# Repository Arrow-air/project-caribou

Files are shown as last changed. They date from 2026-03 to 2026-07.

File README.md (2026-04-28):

# Project Caribou 🦌

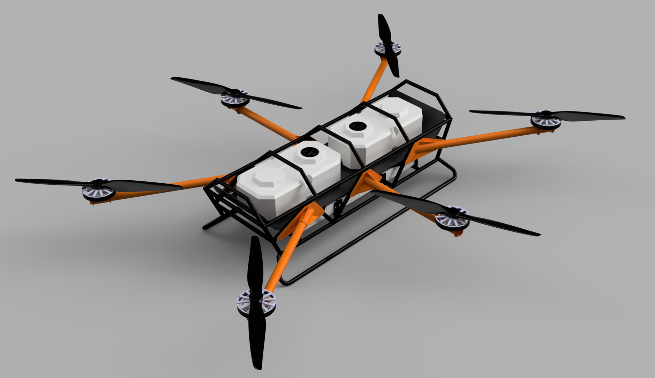
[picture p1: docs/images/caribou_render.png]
Project Caribou


**An open-source heavy-lift hexacopter for cargo logistics and precision agriculture.**

Project Caribou is a ~200 kg MTOW hexacopter with ~100 kg payload capacity, 18–24S power architecture, and ArduPilot firmware. Designed for ruggedness, field repairability, and cost-effective manufacturing. Built on lessons from Project Feather and Project Quiver.

Developed by [Arrow Air](https://arrowair.com) and released under the CERN Open Hardware Licence.

## Key Features

- **Heavy lift** — ~100 kg payload for cargo delivery or 80L liquid spraying
- **Hybrid material airframe** — welded steel/aluminum core with detachable CF or aluminum motor arms
- **High-voltage architecture** — 18–24S (60–100V) with external HV kill switch and redundant power supply
- **Redundant avionics** — triple-redundant IMU, GPS, and compass
- **ArduPilot firmware** — standard QGroundControl/Mission Planner compatibility
- **Field serviceability** — modular arms for transport, replaceable components

## Repository Structure

```
project-caribou/
├── engineering/            # Active design work
│   ├── cad/                # build123d CAD, reference geometry, exports
│   └── electronics/        # Self-contained KiCad PCB projects
│       └── pcbs/
│           ├── CBC_PCB/    # Caribou battery connector PCB, issue #6
│           │   └── kicad/libs/
│           └── CMAIN_PCB/  # Caribou main PCB, issue #8
│               └── kicad/libs/
├── docs/
│   ├── ADRs/               # Architecture Decision Records
│   └── meetings/           # Meeting notes and summaries
├── src/                    # Legacy/general source area
└── CONTRIBUTING.md
```

## Community

- **Discord** — [discord.gg/arrow](https://discord.gg/arrow) — `#project-caribou-general`
- **DAO Forum** — [dao.arrowair.com](https://dao.arrowair.com)

## License

[CERN Open Hardware Licence Version 2 - Strongly Reciprocal (CERN-OHL-S)](https://ohwr.org/cern_ohl_s_v2.txt)

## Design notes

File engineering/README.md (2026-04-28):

# Engineering

This folder contains the active design work for Project Caribou.

- `cad/` — mechanical CAD, generated exports, and reference geometry.
- `electronics/` — PCB projects and electronics design files.

Keep durable decisions and explanatory documents in `docs/`. Use GitHub issues and discussions for live work-in-progress updates, then summarize settled outcomes back into the relevant README or ADR.

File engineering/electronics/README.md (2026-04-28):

# Electronics

Caribou electronics design files live here.

## PCB projects

Each PCB has its own self-contained folder under `pcbs/`. KiCad projects should keep project files under `kicad/` and local libraries under `kicad/libs/` so a contributor can clone/download the PCB folder and open it without missing project-specific components.

Current PCB folders:

- `pcbs/CBC_PCB/` — Caribou battery connector PCB. Tracks [issue #6](https://github.com/Arrow-air/project-caribou/issues/6).
- `pcbs/CMAIN_PCB/` — Caribou main PCB. Tracks [issue #8](https://github.com/Arrow-air/project-caribou/issues/8).

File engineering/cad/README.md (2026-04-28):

# CAD

Caribou CAD work lives here.

## Folders

- `build123d/` — Python/build123d parametric CAD source.
- `reference/` — imported vendor, measurement, or reference geometry.
- `build123d/exports/` — generated STEP/STL outputs for review, manufacturing, or downstream CAD use.

Generated exports should be reproducible from the source where practical. If an export is hand-edited or comes from another CAD package, document that in the nearest README.

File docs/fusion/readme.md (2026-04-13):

# Fusion 360 Workspace — Project Caribou

## Folder Structure

```
📁 Caribou_<Name>        — Personal sandbox (each contributor creates their own)
📁 Deprecated             — Move obsolete files here (do NOT delete)
📁 Main_Assembly          — Master Assembly ONLY (no parts, no features)
📁 Parts/
   ├── EL-Electronics
   ├── EN-Enclosure
   ├── PW-Powertrain
   └── ST-Structure
📁 Sub_Assemblies         — Sub-assemblies composed of parts or other sub-assemblies
```

## Naming Convention

### Parts

Format: `<Category>-<Type>-<Number>-<Description>`

| Example | Meaning |
|---|---|
| `ST-FRM-001-Spacer_1` | Structure — Frame — Part 001 |
| `PW-MTR-001-Motor_Mount` | Powertrain — Motor — Part 001 |
| `EL-PCB-001-BMS_Enclosure` | Electronics — PCB — Part 001 |

### Sub-Assemblies

Format: `<Category>-<Description>_Assembly`

| Example | Meaning |
|---|---|
| `PW-Propulsion_System_Assembly` | Powertrain sub-assembly |
| `ST-Frame_Assembly` | Structure sub-assembly |

### Category Prefixes

| Prefix | Category |
|---|---|
| `ST` | Structure |
| `PW` | Powertrain |
| `EL` | Electronics |
| `EN` | Enclosure |

## Workflow

### Strict Rules

1. **No feature creation in assemblies.** Use Fusion's file type setting — choose either `Assembly` or `Part Design`. **Never use Hybrid.**
2. **Main_Assembly = Assembly only.** Only joints, alignment, and mirroring. No parts are designed here.
3. **Working Assembly Method:**
   - Create a separate assembly file in your personal folder (`Caribou_<Name>`)
   - Insert the parts/sub-assemblies you need from Main_Assembly
   - Do all design work in dedicated Part files under `Parts/`
   - Once finished, insert your part/sub-assembly back into Main_Assembly

### General Workflow

1. **New part?** → Create it in the correct `Parts/<Category>` folder using the naming convention
2. **Testing/iterating?** → Work in your `Caribou_<Name>` sandbox
3. **Part is done?** → Insert into the relevant Sub-Assembly or Main_Assembly
4. **Part is obsolete?** → Move to `Deprecated/` — never delete

## Access

- All contributors get **Edit** access to the Fusion 360 project
- Main_Assembly changes should be communicated in **#caribou-team** before pushing

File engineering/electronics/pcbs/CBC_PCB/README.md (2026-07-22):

# CBC_PCB — Caribou Battery Connector PCB

The Caribou Battery Connector PCB (CBC) interfaces 18S smart battery packs with the Caribou hexacopter electrical system. Each motor arm carries one CBC board connected to one battery, providing power switching, protection, voltage regulation, and dual CAN bus communication.

- **GitHub issue:** [#6 — Design BC-PCB for Caribou: 18S, 100A nominal, 200A spike](https://github.com/Arrow-air/project-caribou/issues/6)
- **Starting point:** Project Quiver BC-PCB KiCad design.
- **EDA Tool:** KiCad 10
- **Initial layout import:** KiCad source is in [`kicad/`](kicad/); import notes are in [`docs/import-2026-05-19-cbc-layout.md`](docs/import-2026-05-19-cbc-layout.md).

## Context within Project Caribou

Project Caribou is a ~200 kg MTOW heavy-lift hexacopter with ~100 kg payload capacity, 18–24S power architecture, and ArduPilot firmware. The aircraft uses 6× Hobbywing XRotor X15 propulsion units, each fed by a dedicated 18S Tattu 4.0 smart battery.

Each of the 6 motor arms has:
- 1× Tattu 4.0 18S battery pack
- **1× CBC_PCB** (this board) — battery interface, protection, regulation
- 1× Hobbywing XRotor X15 motor + ESC

The CBC board sits between the battery and the propulsion unit. It provides:
1. **Battery interface** — receives battery power and battery CAN via the [C90D adapter PCB](../C90D_PCB/), which mates the Tattu 4.0 battery connector
2. **Short-circuit protection** — 250A ceramic fuse
3. **Active power switching** — precharge, kill switch, power enable via MOSFETs
4. **Voltage regulation** — galvanically isolated 12V (GNDE) for the aircraft power distribution, plus non-isolated 5V/3.3V (GNDI) for onboard logic
5. **Dual CAN bus** — battery protocol (CAN 1) and DroneCAN (CAN 2) as bridge
6. **Wireless diagnostics** — WiFi/BLE via ESP32-S3 for configuration and monitoring

The regulated 12V output (GNDE) feeds into the Caribou Main PCB ([CMAIN_PCB](../CMAIN_PCB/)) via the JST JWPF signal connector (J501) harness.

## Concept Renderings

These early renderings show the intended CBC_PCB packaging concept and approximate component placement. They are illustrative only and may change during schematic/layout development.

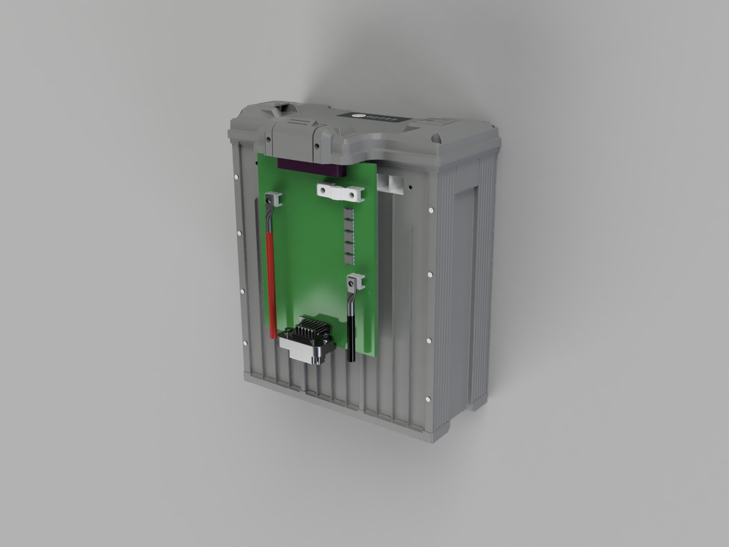
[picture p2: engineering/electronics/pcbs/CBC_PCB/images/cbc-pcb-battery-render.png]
CBC_PCB concept rendering with Tattu battery


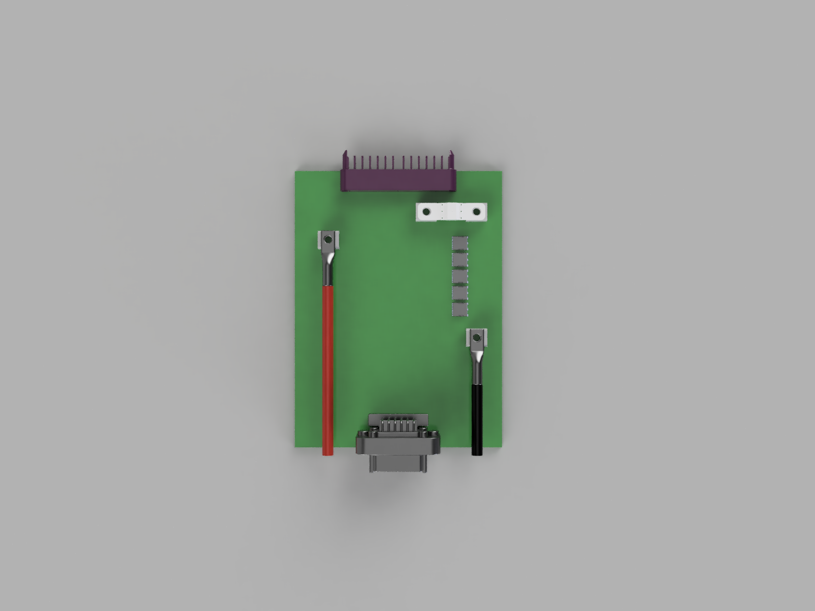
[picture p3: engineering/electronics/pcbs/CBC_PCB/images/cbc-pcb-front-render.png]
CBC_PCB front concept rendering


## Board Overview

```
Battery (18S Tattu 4.0)
        |
        v
+---------------------+
|  C90D Adapter PCB    |  ← Separate board: mates the battery connector,
|  (../C90D_PCB/)      |     bridges present-detect pins
+---------------------+
        |
        v
+---------------------+
|  Power Entry Pads    |  ← Power (+ / −) via HC201/HC202 pads,
|  + Battery CAN       |     CAN L/H from battery via CN201
+---------------------+
|  AMXL-250 Fuse       |  ← 250A short-circuit protection
+---------------------+
|  MOSFETs             |  ← Precharge / Kill switch / Power enable
+---------------------+
|  Screw Terminals     |  ← Red (+) and Black (−) cables
|  (AMT0650009DB0000G) |     to Hobbywing X15 propulsion
+---------------------+
|                       |
|  HV Bus (54–75.6V)   |
|    |            |     |
|    v            v     |
|  [Buck]    [Push-Pull]|
|  5V/1A     12V/10A   |
|  (GNDI)    (isolated) |
|    |        (GNDE)    |
|    v            |     |
|  [LDO]         |     |
|  3.3V          |     |
|  (GNDI)        |     |
+---------------------+
|  JST JWPF Connector  |  ← 12V (GNDE), DroneCAN, signals
|  (J501, 8-pos)       |     to aircraft harness → CMAIN_PCB
+---------------------+
```

## Specifications

| Parameter | Value |
|---|---|
| Configuration | 18S (18 series cell groups) |
| Max Voltage | 75.6V (4.2V × 18) |
| Nominal Voltage | 64.8V (3.6V × 18) |
| Continuous Current | 150A (in line with the C90D power path) |
| Spike Current | 200A (short duration) |
| Board Shape | Rectangular |
| EDA Tool | KiCad 10 |
| Board Layers | TBD |

### Current Rating Justification

Based on the Hobbywing XRotor X15 motor data:

| Throttle | Thrust | Current per Motor |
|---|---|---|
| 51% | 27,257 g | 44.7 A |
| 72% | 47,933 g | 101.6 A |
| 100% | 72,647 g | 197.1 A |

Hover throttle is ~50%. The 150A continuous rating covers normal operations with margin; the 200A spike rating handles full-throttle bursts.

## Connectors and Fuse

### Battery Interface (via C90D Adapter)

The CBC does not mate the battery directly. The Tattu 4.0 pack connector mates with the [C90D adapter PCB](../C90D_PCB/), which carries the battery connector (ACES 59626), bridges the battery-present detection pins, and adapts the connector orientation into the CBC assembly.

From the C90D, the battery reaches the CBC through:

| Interface | Reference | Function |
|---|---|---|
| Power entry pads | HC201 (`H_PWR-IN`), HC202 (`H_PWR-IN--PREFUSE`) | High-current + / − power path from the C90D |
| Battery CAN connector | CN201 (A1257WV-S-2P, 2-pin GH-compatible) | `CANH_BAT` / `CANL_BAT` to the isolated battery CAN interface |

> **Note:** the battery-present detection bridge (required for the Tattu pack to power on) lives on the C90D side — see the C90D documentation for connector and mating details.

### Propulsion Screw Terminals

**Selected: Amphenol Anytek AMT0650009DB0000G**

These are the high-current screw terminals where cables to the Hobbywing X15 propulsion system are connected (+ and −).

| Parameter | Value |
|---|---|
| Type | Screw Terminal, Power Tap |
| Screw Size | M5 |
| Pins | 6 |
| Current Rating | 180A |
| Mounting | Through-Hole DIP |
| Contact Material | Brass + Steel Nut (matte tin plated) |
| Torque | 18 lbf·in |

Two sets of AMT0650009DB0000G screw terminals are used on the board: one pair for the propulsion output (+ / −), and another pair for mounting the main fuse.

### Signal Connector (Drone Interface)

**Selected: JST B08B-JWPF-SK-R (J501)**

This connector interfaces the CBC with the rest of the Caribou electrical system via a wiring harness to the [CMAIN_PCB](../CMAIN_PCB/). The JWPF series is a waterproof wire-to-board connector family; an earlier Amphenol AT13 concept was dropped in favor of JST.

| Pin | Signal | Function |
|---|---|---|
| 1 | GNDE | Isolated ground |
| 2 | GNDE | Isolated ground |
| 3 | 12V_ISOLATED | Isolated 12V output to aircraft LV system |
| 4 | 12V_ISOLATED | Isolated 12V output to aircraft LV system |
| 5 | CANL_DRONE | DroneCAN low |
| 6 | CANH_DRONE | DroneCAN high |
| 7 | 12V_TRIGGER_SIG | Kill switch trigger signal |
| 8 | 12V_SUPPLY | 12V supply input |

The 8 positions carry the isolated 12V output (GNDE), the DroneCAN bus pair, and the kill/control signals to/from the Caribou avionics.

### Main Fuse (Short-Circuit Protection)

**Selected: Eaton AMXL-250**

The main fuse sits between the battery connector and the power output stage, protecting against short circuits. It is mounted on two AMT0650009DB0000G screw terminals (bolt-in design).

| Parameter | Value |
|---|---|
| Type | Automotive bolt-in fuse |
| Current Rating | 250A |
| Voltage Rating | 125 Vdc |
| Body | Ceramic |
| Mounting | Bolt-in (M5 terminals) on 2× AMT0650009DB0000G |

The 250A fuse rating provides short-circuit protection while allowing the full 200A spike current without nuisance blowing. The ceramic body handles the thermal demands of high-current interruption.

## MCU and Communication

### MCU: ESP32-S3-WROOM-1 (U301)

The ESP32-S3-WROOM-1 module (N16R8 variant) is a dual-core microcontroller with integrated wireless connectivity. It includes a PCB antenna — no external antenna components are required. A keepout zone must be maintained around the antenna area on the PCB layout (no copper / ground plane underneath).

| Parameter | Value |
|---|---|
| Core | 2× 32-bit Xtensa LX7, up to 240 MHz |
| Flash | 16 MB (N16R8) |
| PSRAM | 8 MB (N16R8) |
| WiFi | 802.11 b/g/n (2.4 GHz) |
| Bluetooth | BLE 5.0 |
| Operating Voltage | 3.0–3.6V |
| Antenna | Integrated PCB antenna |

### Dual CAN Bus (2× MCP2515 + Transceiver)

Two independent CAN networks using external MCP2515 controllers on a shared SPI bus. This provides identical timing behavior on both buses and clean separation of the battery-side and drone-side CAN domains.

| CAN Bus | Purpose | Controller | Transceiver |
|---|---|---|---|
| CAN 1 — Battery | Battery protocol (smart battery communication) | MCP2515 (U402, SPI, CS1) | ADM3053BRWZ (U404, galvanically isolated) |
| CAN 2 — Drone | DroneCAN (UAVCAN v0) interface to Caribou avionics | MCP2515 (U401, SPI, CS2) | TJA1049T/3J (U403) |

The battery CAN transceiver (ADM3053) has an integrated isolated DC-DC converter, so the battery-side CAN domain is galvanically isolated from the board logic. Each MCP2515 is clocked by a 16 MHz crystal (X401/X402). 120 Ω termination resistors are jumper-selectable and open by default.

The board converts between the battery protocol (CAN 1) and DroneCAN (CAN 2). The DroneCAN bus connects via the J501 signal connector through the wiring harness to the [CMAIN_PCB](../CMAIN_PCB/), which serves as the central avionics hub for all 6 motor arms.

### Schematic Sheet Interfaces

| Signal / rail | Source sheet | Destination sheet(s) | Direction / notes |
|---|---|---|---|
| `H_PWR-IN`, `H_PWR-IN-`, `H_PWR-IN--PREFUSE` | POWER SECTION | POWER SECTION / board power path | 18S battery high-current domain; main fuse is mounted on two of the AMT screw terminals (J201–J204). |
| `+5V` | POWER REGULATOR | ESP32 SECTION, CAN SECTION, PERIPHERALS | Internal non-isolated logic rail. |
| `+3V3` | POWER REGULATOR | ESP32 SECTION, CAN SECTION, PERIPHERALS | ESP32, MCP2515, CAN transceivers, sensors. |
| `12V_ISOLATED` | POWER REGULATOR | PERIPHERALS / J501 connector | Isolated output to aircraft harness; add an output fuse before harness output. |
| `ESP_ENABLE_SIGNAL` | ESP32 SECTION | POWER SECTION | ESP-controlled main MOSFET latch enable (latch: `U201` 74LVC2G02); latch output default-low via `R207` pulldown. |
| `PRECHARGE_ESP_SIGNAL` | ESP32 SECTION | POWER SECTION | ESP-controlled precharge command. |
| `SCHMITT_OUT` | POWER SECTION | ESP32 SECTION | Hardware kill/trigger state feedback to ESP32. |
| `SCK`, `MOSI`, `MISO` | ESP32 SECTION / CAN SECTION | ESP32 ↔ dual MCP2515 | Shared SPI bus; `SCK`/`MOSI` from ESP32, `MISO` from MCP2515s. |
| `CS#1`, `CS#2` | ESP32 SECTION | CAN SECTION | MCP2515 chip-selects; add pull-ups so controllers remain deselected during ESP32 reset/boot. |
| `INT#1`, `INT#2` | CAN SECTION | ESP32 SECTION | MCP2515 interrupt outputs; ESP32 pull-up usage is documented in firmware/hardware notes. |
| `RESET1`, `RESET2` | ESP32 SECTION | CAN SECTION | MCP2515 resets from ESP32. |
| `TEMP1_DQ`, `TEMP2_DQ` | ESP32 SECTION / PERIPHERALS | ESP32 ↔ temperature sensors | 1-Wire data nets; formerly `DATA1` / `DATA2`. |
| `CANH_BAT`, `CANL_BAT` | CAN SECTION / POWER SECTION | Battery connector ↔ CAN 1 | Battery CAN pair only; no battery CAN ground is normally carried. |
| `CANH_DRONE`, `CANL_DRONE` | CAN SECTION / PERIPHERALS | CAN 2 ↔ J501 harness | DroneCAN pair to CMAIN_PCB; termination is jumper-selectable and normally open. |
| `GND_CA`, `GND_CB`, `GNDI`, `GNDE` | Multiple | Domain-specific returns | `GND_CA` is effectively unused unless battery CAN reference is later required. `GND_CB` may be tied with other CBC `GND_CB` references on CMAIN_PCB. |

### GPIO Allocation

As routed on the ordered board (from the production netlist):

| Function | Signal | ESP32-S3 GPIO |
|---|---|---|
| Precharge command | `PRECHARGE_ESP_SIGNAL` | IO4 |
| Kill/trigger state feedback | `SCHMITT_OUT` | IO5 |
| Main MOSFET latch enable | `ESP_ENABLE_SIGNAL` | IO6 |
| Temperature sensors (1-Wire, DS18B20) | `TEMP2_DQ` / `TEMP1_DQ` | IO7 / IO15 |
| Shared SPI — MOSI, SCK, MISO | `MOSI` / `SCK` / `MISO` | IO11 / IO12 / IO13 |
| MCP2515 #1 (Battery CAN) — CS, INT, RESET | `CS#1` / `INT#1` / `RESET1` | IO10 / IO21 / IO48 |
| MCP2515 #2 (Drone CAN) — CS, INT, RESET | `CS#2` / `INT#2` / `RESET2` | IO14 / IO47 / IO9 |

## Functional Requirements

### Power Path

- **High-side MOSFET switching** — N-channel MOSFETs with charge pump gate drive
- **Precharge circuit** — soft-start via resistor + relay/MOSFET to limit inrush current
- **Emergency kill switch** — hardware-level kill input, independent of MCU. Connects to the Caribou external HV kill switch via the AT signal connector.
- **Main fuse** — Eaton AMXL-250 (250A) bolt-in fuse for short-circuit protection

### Voltage Regulation

The power supply architecture uses two independent stages with full galvanic isolation between internal onboard logic (GNDI) and external drone systems (GNDE).

#### Internal Supply (GNDI — non-isolated)

Provides power for onboard logic (ESP32, MCP2515, CAN transceivers, gate drivers, sensors).

| Stage | Topology | IC | Input | Output | Notes |
|---|---|---|---|---|---|
| 5V Rail | Sync Buck | e.g. MP9487 or similar (100V+, integrated FETs, ≥1A) | 54–75.6V (HV Bus) | 5V / 1A | Main internal rail |
| 3.3V Rail | LDO | e.g. AMS1117-3.3 or similar | 5V | 3.3V | ESP32, MCP2515, CAN transceivers |

#### External Supply (GNDE — galvanically isolated)

Provides isolated 12V output for the Caribou aircraft power distribution via the [CMAIN_PCB](../CMAIN_PCB/).

| Stage | Topology | IC | Input | Output | Notes |
|---|---|---|---|---|---|
| 12V Rail | Isolated Push-Pull | TBD | 54–75.6V (HV Bus) | 12V / 10A (isolated, GNDE) | Powers aircraft avionics, sensors, servos via CMAIN_PCB |

The isolation barrier between GNDI and GNDE ensures that a fault on the aircraft power bus does not back-feed into the battery management logic.

## Folder Layout

```
CBC_PCB/
├── README.md               ← this file
├── docs/                   ← board-specific notes, requirements, design docs
│   ├── connector-pinout.md ← connector/harness pinout and wiring notes
│   ├── power-architecture.md ← power tree and protection notes
│   └── schematic-review-followup.md ← schematic review action register
├── firmware/               ← board-specific firmware (ESP32-S3)
├── images/                 ← board renders, screenshots, diagrams, photos
├── kicad/                  ← KiCad 10 project files
│   └── libs/               ← project-local KiCad libraries
│       ├── 3dmodels/       ← project-local 3D models
│       ├── CBC_PCB.pretty/ ← project-local footprint library
│       └── CBC_PCB.kicad_sym ← project-local symbol library
└── manufacturing/          ← Gerbers, BOM, assembly drawings, pick-and-place
```

## Related

- [CMAIN_PCB](../CMAIN_PCB/) — Caribou Main PCB (central avionics hub)
- [Project Caribou](https://github.com/Arrow-air/project-caribou) — parent project
- [Issue #6](https://github.com/Arrow-air/project-caribou/issues/6) — tracking issue for this board
- [Issue #8](https://github.com/Arrow-air/project-caribou/issues/8) — CMAIN_PCB tracking issue

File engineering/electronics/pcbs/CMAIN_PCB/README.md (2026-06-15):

# CMAIN_PCB — Caribou Main PCB

Caribou PCB project.

- GitHub issue: [#8 — Design Caribou main PCB: merge Feather PDB and Quiver main PCB](https://github.com/Arrow-air/project-caribou/issues/8)
- Starting point: Project Feather PDB and Project Quiver main PCB.
- Scope: low-voltage/signal-level avionics integration, 6-motor outputs, ArduPilot/CAN architecture, ESC signal outputs, sensor connections, and central-frame form factor. High-voltage/current handling is out of scope.
- External 3D viewer / Fusion share link: <https://a360.co/4xzUs3s>
- STEP export: [`manufacturing/CMAIN_PCB.step`](manufacturing/CMAIN_PCB.step)

## Connector Requirements

Initial connector requirements are tracked in [`docs/connector-requirements.md`](docs/connector-requirements.md). Current assumptions include:

- 6× CBC_PCB interfaces using `AT13-12PB-BM03` 12-pin connectors.
- 6× ESC interfaces using `AT13-6P-BM01GRY` 6-pin connectors with `CAN H`, `CAN L`, `PWM`, `GND`, `GND`, and `NC`.
- Additional external sensor / attachment connectors are still TBD pending board-space and component-placement checks.

## Folder layout

- `docs/` — board-specific notes, requirements, and design documentation.
- `firmware/` — board-specific firmware, configuration, or embedded code if needed.
- `images/` — board renders, screenshots, diagrams, and photos.
- `kicad/` — KiCad project files.
- `kicad/libs/` — project-local KiCad libraries.
- `kicad/libs/3dmodels/` — project-local 3D models.
- `kicad/libs/CMAIN_PCB.pretty/` — project-local footprint library.
- `kicad/libs/CMAIN_PCB.kicad_sym` — project-local symbol library.
- `manufacturing/` — generated manufacturing outputs such as Gerbers, BOM, assembly drawings, and pick-and-place files.

Add the KiCad project files directly under `kicad/` when design work starts. Keep project-specific components in `kicad/libs/` so the PCB can be opened without missing custom symbols, footprints, or 3D models.

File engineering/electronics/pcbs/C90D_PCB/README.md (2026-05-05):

# C90D_PCB — Caribou 90° Battery Adapter PCB

The Caribou 90° adapter PCB (`C90D_PCB`) sits between the main battery connector and the `CBC_PCB`. It adapts the battery connector orientation into the CBC assembly while carrying the propulsion power path for a Hobbywing XRotor X15-based motor arm.

- **GitHub issue:** [#19 — Create C90D_PCB - An 90° adapter PCB interacting with the CBC_PCB and the battery](https://github.com/Arrow-air/project-caribou/issues/19)
- **Related PCB:** [`CBC_PCB`](../CBC_PCB/)
- **EDA Tool:** KiCad 10

## Board Purpose

`C90D_PCB` is a mechanical and electrical adapter:

1. **Battery-side interface** — mates with the main battery connector.
2. **CBC-side interface** — presents a right-angle power connection into the `CBC_PCB` assembly.
3. **High-current path** — carries the Hobbywing X15 drive current.
4. **Mechanical support** — includes mounting holes so the adapter and connector assembly can be secured.

## Main Parts / Connectors

- Main battery connector: `ACES 59626`
- CAN connector: `BM02B-GHS-TBT(LF)(SN)`
- Right-angle screw terminal / power interface to the `CBC_PCB`: `OT-201-M8`

## Initial Requirements

| Parameter | Target / Notes |
|---|---|
| Function | 90° adapter between battery connector and `CBC_PCB` |
| Propulsion load | Hobbywing XRotor X15 current draw |
| Current design target | 150 A, pending detailed validation |
| Mounting | Include mounting holes for the PCB / connector assembly |
| Board constraints | Copper weight, current path geometry, connector ratings, thermal rise, and mechanical assembly must be checked against the 150 A target |

## Reference Renderings

The initial GitHub issue includes basic renderings showing the main component arrangement and intended 90° adapter concept. Treat these as layout/mechanical references for early design work; detailed placement and mounting geometry still need validation in CAD/KiCad.

- [Rendering 1](https://github.com/user-attachments/assets/765d904a-0705-4a9c-978a-a3602e707b37)
- [Rendering 2](https://github.com/user-attachments/assets/26fbdbea-c981-408a-b00c-e627d38056d7)

## Folder Layout

- `docs/` — board-specific notes, requirements, and design documentation.
- `firmware/` — board-specific firmware, configuration, or embedded code if needed.
- `images/` — board renders, screenshots, diagrams, and photos.
- `kicad/` — KiCad project files.
- `kicad/libs/` — project-local KiCad libraries.
- `kicad/libs/3dmodels/` — project-local 3D models.
- `kicad/libs/C90D_PCB.pretty/` — project-local footprint library.
- `kicad/libs/C90D_PCB.kicad_sym` — project-local symbol library.
- `manufacturing/` — generated manufacturing outputs such as Gerbers, BOM, assembly drawings, and pick-and-place files.

Add the KiCad project files directly under `kicad/` when design work starts. Keep project-specific components in `kicad/libs/` so the PCB can be opened without missing custom symbols, footprints, or 3D models.

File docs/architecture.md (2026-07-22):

---
title: System Architecture
sidebar_label: Architecture
sidebar_position: 2
description: How Project Caribou is put together — airframe, propulsion, power, electronics, and avionics
---

# System Architecture

Caribou is a ~200 kg MTOW hexacopter organized around a simple structural idea: **six independent motor arms around a central core**. Each arm is a self-contained power unit — battery, power electronics, motor — and the core carries the avionics, low-voltage distribution, and payload.

:::note
This page covers the parts of the architecture that are documented in the repository today. Some areas (notably the structure and detailed avionics configuration) are still being written up as PT1 progresses — see the [PT1 status](./index.md#development-status) on the intro page.
:::

## Architecture at a Glance

```text
CENTRAL CORE
  - Flight controller (ArduPilot)
  - CMAIN PCB (LV distribution + CAN hub)
  - Payload interfaces
      |
      |  harness per arm: isolated 12V,
      |  DroneCAN, kill/control signals
      |
MOTOR ARM (x6)
  Tattu 4.0 18S battery
   -> C90D adapter PCB
   -> CBC PCB (fuse, precharge, kill, regulation, dual CAN)
   -> Hobbywing X15 motor + ESC with 63" propeller
```

## Propulsion

Six Hobbywing XRotor X15 integrated propulsion units (motor + ESC) with 63" (1600 mm) propellers, rated by Hobbywing at 32.5–37.5 kg working thrust and up to 72 kg maximum thrust per rotor. Hover sits around 50% throttle (~45 A per motor); full throttle draws close to 200 A per motor, which drives the current ratings throughout the power path.

ESCs take CAN and PWM signal inputs, connected to CMAIN via waterproof JST JWPF connectors.

## Power

**Per-arm, no shared HV bus.** Each arm has its own 18S Tattu 4.0 smart battery (64.8 V nominal, 75.6 V max) feeding only its own motor through its own [CBC board](./electronics/cbc.md). PT1 flies at 18S; the platform is specified for an 18–24S architecture.

Key properties of the power design:

- **Fused and switched per arm** — 250 A ceramic fuse, MOSFET precharge and main-enable stages on every CBC
- **Hardware kill chain** — an external HV kill switch feeds every CBC through the harness and cuts motor power at the MOSFET stage, independent of firmware
- **Isolated low-voltage system** — each CBC generates a galvanically isolated 12 V / 10 A output; these feed the aircraft LV system through CMAIN, so aircraft-side faults cannot back-feed into any battery power path
- **Smart battery telemetry** — each CBC reads its pack over the battery's CAN protocol and republishes telemetry on DroneCAN, so the autopilot monitors all six packs with standard battery monitors

## Electronics

Three custom KiCad-designed boards — CBC (×6), C90D (×6), and CMAIN (×1) — covered in detail in the [Electronics section](./electronics/index.md).

## Avionics

- **ArduPilot** flight stack, compatible with QGroundControl and Mission Planner
- **Triple-redundant IMU, GPS, and compass**
- **DroneCAN** as the aircraft-wide bus for battery telemetry and ESC communication, routed through CMAIN

## Structure

The airframe uses a welded steel/aluminum core structure with detachable motor arms (carbon fiber or aluminum) for transport and field service. The PT1 test frame is built; structural documentation (materials, dimensions, analysis) is part of the in-progress PT1 engineering report.

## Design Lineage

Caribou deliberately reuses proven patterns from earlier Arrow aircraft: the CBC evolved from Quiver's battery connector PCB, CMAIN merges the Feather PDB with Quiver's main PCB, and the smart-battery + DroneCAN approach extends what Quiver established. Where Caribou differs is scale — per-arm batteries instead of a central pack, an order of magnitude more thrust per rotor, and high-voltage safety hardware (kill chain, precharge, isolation) sized accordingly.

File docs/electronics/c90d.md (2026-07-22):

---
title: C90D — 90° Battery Adapter PCB
sidebar_label: C90D (Battery Adapter)
sidebar_position: 3
description: The 90° adapter PCB between the battery connector and the CBC assembly
---

# C90D — 90° Battery Adapter PCB

The C90D is a mechanical and electrical adapter between the main battery connector and the [CBC](./cbc.md) assembly. It changes the battery connector orientation by 90° to suit the motor-arm packaging while carrying the full propulsion power path.

Source: [`engineering/electronics/pcbs/C90D_PCB/`](https://github.com/Arrow-air/project-caribou/tree/main/engineering/electronics/pcbs/C90D_PCB) · Tracking issue: [#19](https://github.com/Arrow-air/project-caribou/issues/19)

## What It Does

1. **Battery-side interface** — mates with the main battery connector (ACES 59626)
2. **CBC-side interface** — right-angle power connection into the CBC assembly via OT-201-M8 screw terminals
3. **High-current path** — carries the Hobbywing X15 drive current (150 A design target, pending detailed validation)
4. **Battery CAN passthrough** — dedicated CAN connector (JST GH series)
5. **Mechanical support** — mounting holes secure the adapter and connector assembly

## Design Notes

Because the board is a pure power/signal passthrough, the design work is dominated by physical constraints: copper weight, current path geometry, connector ratings, thermal rise, and mechanical assembly — all checked against the 150 A target.

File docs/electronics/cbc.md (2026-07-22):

---
title: CBC — Battery Connector PCB
sidebar_label: CBC (Battery Connector)
sidebar_position: 2
description: The Caribou Battery Connector PCB — power switching, protection, regulation, and dual CAN per motor arm
---

# CBC — Caribou Battery Connector PCB

The CBC sits between an 18S Tattu 4.0 smart battery and a Hobbywing X15 propulsion unit. Each of the six motor arms carries one CBC. It is the safety-critical board in the power path: nothing flows from a battery to a motor except through a CBC.

Source: [`engineering/electronics/pcbs/CBC_PCB/`](https://github.com/Arrow-air/project-caribou/tree/main/engineering/electronics/pcbs/CBC_PCB) · Tracking issue: [#6](https://github.com/Arrow-air/project-caribou/issues/6)

## What It Does

1. **Battery mating** — mates directly with the Tattu 4.0 battery connector (via the [C90D adapter](./c90d.md)). Battery-present detection pins must be bridged for the pack to power on
2. **Short-circuit protection** — 250 A ceramic bolt-in fuse (Eaton AMXL-250)
3. **Active power switching** — MOSFET stage with three functions:
   - *Precharge* — soft-starts the ESC input capacitors through a resistor before the main path closes, limiting inrush current
   - *Main power enable* — low-Rdson parallel MOSFETs connect the HV bus to the propulsion output
   - *Kill switch* — hardware-level cutoff driven by the aircraft's external HV kill switch, independent of the MCU
4. **Voltage regulation** — 5 V / 3.3 V rails for onboard logic (GNDI, non-isolated) and a galvanically isolated 12 V / 10 A output (GNDE) that powers the aircraft's low-voltage system through CMAIN
5. **Dual CAN** — battery protocol on one bus, DroneCAN on the other, bridged in firmware

## Key Specifications

| Parameter | Value |
|---|---|
| Battery configuration | 18S (64.8 V nominal, 75.6 V max) |
| Continuous current | 150 A (in line with the C90D power path) |
| Spike current | 200 A (short duration) |
| Main fuse | 250 A ceramic bolt-in |
| Isolated output | 12 V / 10 A (GNDE) |
| MCU | ESP32-S3-WROOM-1 |
| CAN controllers | 2× MCP2515 on shared SPI |
| EDA tool | KiCad |

The current ratings are derived from Hobbywing X15 motor data: roughly 45 A per motor at hover throttle (~50%), ~100 A at 72% throttle, and ~197 A at full throttle.

## Dual CAN Bridge

The CBC has two independent CAN interfaces:

- **CAN 1 — Battery** — private bus to the Tattu 4.0 smart battery. This interface is galvanically isolated, so the battery-side CAN domain stays separate from the board logic
- **CAN 2 — DroneCAN** — aircraft-wide bus to the flight controller via CMAIN

Firmware decodes the battery pack telemetry (voltage, current, state of charge, cell data, temperatures) and republishes it as standard DroneCAN battery messages, so the autopilot sees each pack as a normal DroneCAN battery monitor. CAN termination is jumper-selectable and open by default.

## Firmware

Firmware for the ESP32-S3 is in review ([PR #54](https://github.com/Arrow-air/project-caribou/pull/54)): switch control (precharge/enable/kill sensing), dual-CAN drivers, Tattu battery telemetry decode, and the DroneCAN bridge.

Bench validation (July 2026) on the manufactured boards: full Tattu telemetry decode on real hardware, and two CBCs connected to a flight controller successfully completed DroneCAN dynamic node allocation, with battery voltage/SoC/temperature visible in Mission Planner via standard `BATT_MONITOR` DroneCAN configuration.

## Status

Manufactured CBC boards were delivered in mid-July 2026 and are in bench bring-up, with enclosures printed. See the board's [`docs/`](https://github.com/Arrow-air/project-caribou/tree/main/engineering/electronics/pcbs/CBC_PCB/docs) folder for the power architecture, connector pinout, and schematic review notes.

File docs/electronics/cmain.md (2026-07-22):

---
title: CMAIN — Main PCB
sidebar_label: CMAIN (Main PCB)
sidebar_position: 4
description: The Caribou Main PCB — central low-voltage avionics hub for all six motor arms
---

# CMAIN — Caribou Main PCB

CMAIN is the central hub of the Caribou electrical system. It merges the roles of the Feather PDB and the Quiver main PCB: low-voltage power distribution, CAN routing, ESC signal outputs, and sensor connections for the whole aircraft. High-voltage/high-current handling is deliberately out of scope — that lives on the [CBC](./cbc.md) boards at each arm.

Source: [`engineering/electronics/pcbs/CMAIN_PCB/`](https://github.com/Arrow-air/project-caribou/tree/main/engineering/electronics/pcbs/CMAIN_PCB) · Tracking issue: [#8](https://github.com/Arrow-air/project-caribou/issues/8)

## Interfaces

| Quantity | Connector | Purpose |
|---|---|---|
| 6 | JST JWPF 8-pin (B08B-JWPF-SK-R) | One per CBC — isolated 12 V in, DroneCAN, kill/control signals |
| 6 | JST JWPF 4-pin (B04B-JWPF-SK-R) | One per Hobbywing X15 ESC — CAN H, CAN L, PWM, GND |

External wire-to-board interfaces use the JST JWPF waterproof connector family (an earlier Amphenol AT13 concept was dropped in favor of JST). Smaller JST GH connectors are used for internal signal-level connections. The board also carries sensor and payload interfaces per the schematic — GNSS (including a DroneCAN RTK option), front and altimeter radar, SIYI gimbal/camera, safety switch, and a companion computer header — plus auxiliary power outputs.

## Scope

- Aggregates six isolated 12 V feeds from the CBCs into the aircraft low-voltage system
- Routes the aircraft-wide DroneCAN network between CBCs, ESCs, and the flight controller
- Provides ESC signal interfaces (CAN + PWM) for the six Hobbywing X15 propulsion units
- Central-frame form factor, mounted in the aircraft core

## Status

CMAIN boards are manufactured and were delivered in July 2026, with 3D-printed enclosures complete. Detailed docs — connector requirements, routing rules, footprint audits, and design proposals — live in the board's [`docs/`](https://github.com/Arrow-air/project-caribou/tree/main/engineering/electronics/pcbs/CMAIN_PCB/docs) folder.

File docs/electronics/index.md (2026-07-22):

---
title: Electronics Overview
sidebar_label: Overview
sidebar_position: 1
description: Overview of the Caribou custom electronics — CBC, C90D, and CMAIN boards
---

# Electronics Overview

Caribou uses a small family of custom PCBs, all designed in KiCad and developed in the open in [`engineering/electronics/pcbs/`](https://github.com/Arrow-air/project-caribou/tree/main/engineering/electronics/pcbs). The architecture builds on the Feather PDB and Quiver PCB designs.

## Board Family

- **[CBC — Caribou Battery Connector PCB](./cbc.md)** (6 per aircraft, one per motor arm) — interfaces an 18S smart battery with a motor arm: power switching, protection, voltage regulation, and dual CAN communication
- **[C90D — 90° Battery Adapter PCB](./c90d.md)** (6 per aircraft) — mechanical/electrical adapter between the battery connector and the CBC assembly
- **[CMAIN — Caribou Main PCB](./cmain.md)** (1 per aircraft) — central low-voltage avionics hub connecting all six arms to the flight controller

## Per-Arm Power Architecture

Each of the six motor arms is an independent power unit:

```text
Tattu 4.0 18S battery
        |
     [C90D]  90-degree adapter
        |
     [CBC]   fuse / precharge / kill / regulation / CAN
      |   \
      |    \-- isolated 12V + DroneCAN + signals --> harness --> CMAIN
      |
 [Hobbywing X15]  motor + ESC
```

There is no shared high-voltage bus between arms — each battery feeds its own propulsion unit through its own CBC. The CBC's galvanically isolated 12V output feeds the aircraft's low-voltage system via CMAIN, so a fault on the aircraft LV bus cannot back-feed into the battery power path.

## CAN Topology

Two separate CAN domains:

- **Battery CAN (per arm)** — each CBC talks to its own Tattu 4.0 smart battery on a private CAN bus, reading pack telemetry (voltage, current, state of charge, temperatures)
- **DroneCAN (aircraft-wide)** — the CBCs, ESCs, and flight controller share the aircraft DroneCAN network, routed through CMAIN. Each CBC translates its battery's telemetry onto DroneCAN so the autopilot sees six standard battery monitors

## Ground Domains

The electronics maintain strict ground-domain separation, labeled consistently across schematics and harnesses:

- **GNDI** — internal, non-isolated logic ground on each CBC (MCU, CAN controllers)
- **GNDE** — isolated external ground for the aircraft power distribution (12V system)

Deeper design detail — connector pinouts, power architecture, requirements, and review notes — lives with each board in the repository and in the pages linked above.

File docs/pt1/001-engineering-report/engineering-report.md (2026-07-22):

---
title: PT1 Engineering Report
draft: true
---

# Caribou PT1 Engineering Report

**Status:** In progress  
**Phase:** PT1 — Proof of Concept  
**Goal:** Validate structural integrity and power architecture. Milestone: stable tethered hover flight.

---

## 1. Overview

_Placeholder — describe the PT1 build scope and objectives._

## 2. Frame

_Placeholder — materials, dimensions, FEA results, build notes._

## 3. Propulsion

_Placeholder — motor selection, ESC, prop sizing, thrust measurements._

## 4. Power Architecture

_Placeholder — battery configuration, voltage, current limits, HV safety._

## 5. Avionics

_Placeholder — flight controller, GPS, telemetry, wiring._

## 6. Test Results

_Placeholder — tethered hover data, issues found, lessons learned._

## 7. Next Steps

_Placeholder — recommendations for PT2._

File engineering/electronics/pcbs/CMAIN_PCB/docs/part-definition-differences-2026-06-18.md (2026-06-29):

<!-- cspell: disable -->
# CMAIN part-choice differences to review (not changed)

Generated while cleaning schematic Value fields. These are cases where the uploaded JLCPCB BOM Tool match differs from the current schematic manufacturer part and/or non-generated footprint metadata. I did **not** apply these part-choice changes.

- Difference rows: **147**
- matched footprint differs: **85**
- matched part differs: **83**

## Differences
- `C1`: schematic `100nF 50V` / MPN `CC0805KRX7R9BB104` / footprint `C_0805_2012Metric` → JLC match `CC0805KRX7R9BB104` (`C49678`) / footprint `fp_71505040a9`. Reason: matched footprint differs.
- `C10`: schematic `10uF 50V` / MPN `GCM31CC71E106KA03L` / footprint `C1206` → JLC match `CL31A106KBHNNNE` (`C13585`) / footprint `C1206`. Reason: matched part differs.
- `C11`: schematic `10uF 50V` / MPN `GCM31CC71E106KA03L` / footprint `C1206` → JLC match `CL31A106KBHNNNE` (`C13585`) / footprint `C1206`. Reason: matched part differs.
- `C12`: schematic `10uF 50V` / MPN `GCM31CC71E106KA03L` / footprint `C1206` → JLC match `CL31A106KBHNNNE` (`C13585`) / footprint `C1206`. Reason: matched part differs.
- `C13`: schematic `100uF 100V` / MPN `EEU-FC1E101S` / footprint `CAP-TH_BD10.0-P5.00-D0.6-FD_2` → JLC match `PA100V100M10x12` (`C46550452`) / footprint `CAP-TH_BD10.0-P5.00-D0.6-FD_2`. Reason: matched part differs.
- `C14`: schematic `100uF 100V` / MPN `EEU-FC1E101S` / footprint `CAP-TH_BD10.0-P5.00-D0.6-FD_2` → JLC match `PA100V100M10x12` (`C46550452`) / footprint `CAP-TH_BD10.0-P5.00-D0.6-FD_2`. Reason: matched part differs.
- `C15`: schematic `10uF 50V` / MPN `GCM31CC71E106KA03L` / footprint `C1206` → JLC match `CL31A106KBHNNNE` (`C13585`) / footprint `C1206`. Reason: matched part differs.
- `C16`: schematic `10uF 50V` / MPN `GCM31CC71E106KA03L` / footprint `C1206` → JLC match `CL31A106KBHNNNE` (`C13585`) / footprint `C1206`. Reason: matched part differs.
- `C17`: schematic `100uF 100V` / MPN `EEU-FC1E101S` / footprint `CAP-TH_BD10.0-P5.00-D0.6-FD_2` → JLC match `PA100V100M10x12` (`C46550452`) / footprint `CAP-TH_BD10.0-P5.00-D0.6-FD_2`. Reason: matched part differs.
- `C18`: schematic `100uF 100V` / MPN `EEU-FC1E101S` / footprint `CAP-TH_BD10.0-P5.00-D0.6-FD_2` → JLC match `PA100V100M10x12` (`C46550452`) / footprint `CAP-TH_BD10.0-P5.00-D0.6-FD_2`. Reason: matched part differs.
- `C2`: schematic `0.1uF 50V` / MPN `—` / footprint `C_0805_2012Metric` → JLC match `CC0805KRX7R9BB104` (`C49678`) / footprint `CC0805KRX7R9BB104`. Reason: matched footprint differs.
- `C20`: schematic `100uF 100V` / MPN `EEU-FC1E101S` / footprint `CAP-TH_BD10.0-P5.00-D0.6-FD_2` → JLC match `PA100V100M10x12` (`C46550452`) / footprint `CAP-TH_BD10.0-P5.00-D0.6-FD_2`. Reason: matched part differs.
- `C21`: schematic `100uF 100V` / MPN `EEU-FC1E101S` / footprint `CAP-TH_BD10.0-P5.00-D0.6-FD_2` → JLC match `PA100V100M10x12` (`C46550452`) / footprint `CAP-TH_BD10.0-P5.00-D0.6-FD_2`. Reason: matched part differs.
- `C25`: schematic `1uF 50V` / MPN `—` / footprint `C_0805_2012Metric` → JLC match `CL21B105KBFNNNE` (`C28323`) / footprint `CC0805KRX7R9BB104`. Reason: matched footprint differs.
- `C26`: schematic `0.1uF 50V` / MPN `—` / footprint `C_0805_2012Metric` → JLC match `CC0805KRX7R9BB104` (`C49678`) / footprint `CC0805KRX7R9BB104`. Reason: matched footprint differs.
- `C27`: schematic `100nF 50V` / MPN `CC0805KRX7R9BB104` / footprint `C_0805_2012Metric` → JLC match `CC0805KRX7R9BB104` (`C49678`) / footprint `fp_71505040a9`. Reason: matched footprint differs.
- `C28`: schematic `100nF 50V` / MPN `CC0805KRX7R9BB104` / footprint `C_0805_2012Metric` → JLC match `CC0805KRX7R9BB104` (`C49678`) / footprint `fp_71505040a9`. Reason: matched footprint differs.
- `C29`: schematic `0.47uF 50V` / MPN `CC0805KKX7R9BB474` / footprint `C_0805_2012Metric` → JLC match `CL21B474KBFNNNE` (`C13967`) / footprint `0805`. Reason: matched part differs.
- `C3`: schematic `100nF 50V` / MPN `CC0805KRX7R9BB104` / footprint `C_0805_2012Metric` → JLC match `CC0805KRX7R9BB104` (`C49678`) / footprint `fp_71505040a9`. Reason: matched footprint differs.
- `C30`: schematic `0.47uF 50V` / MPN `CC0805KKX7R9BB474` / footprint `C_0805_2012Metric` → JLC match `CL21B474KBFNNNE` (`C13967`) / footprint `0805`. Reason: matched part differs.
- `C31`: schematic `100nF 50V` / MPN `CC0805KRX7R9BB104` / footprint `C_0805_2012Metric` → JLC match `CC0805KRX7R9BB104` (`C49678`) / footprint `fp_71505040a9`. Reason: matched footprint differs.
- `C32`: schematic `0.47uF 50V` / MPN `CC0805KKX7R9BB474` / footprint `C_0805_2012Metric` → JLC match `CL21B474KBFNNNE` (`C13967`) / footprint `0805`. Reason: matched part differs.
- `C33`: schematic `0.1uF 50V` / MPN `—` / footprint `C_0805_2012Metric` → JLC match `CC0805KRX7R9BB104` (`C49678`) / footprint `CC0805KRX7R9BB104`. Reason: matched footprint differs.
- `C35`: schematic `0.1uF 50V` / MPN `—` / footprint `C_0805_2012Metric` → JLC match `CC0805KRX7R9BB104` (`C49678`) / footprint `CC0805KRX7R9BB104`. Reason: matched footprint differs.
- `C36`: schematic `0.1uF 50V` / MPN `—` / footprint `C_0805_2012Metric` → JLC match `CC0805KRX7R9BB104` (`C49678`) / footprint `CC0805KRX7R9BB104`. Reason: matched footprint differs.
- `C37`: schematic `1uF 50V` / MPN `—` / footprint `C_0805_2012Metric` → JLC match `CL21B105KBFNNNE` (`C28323`) / footprint `CC0805KRX7R9BB104`. Reason: matched footprint differs.
- `C4`: schematic `100nF 50V` / MPN `CC0805KRX7R9BB104` / footprint `C_0805_2012Metric` → JLC match `CC0805KRX7R9BB104` (`C49678`) / footprint `fp_71505040a9`. Reason: matched footprint differs.
- `C40`: schematic `0.1uF 50V` / MPN `—` / footprint `C_0805_2012Metric` → JLC match `CC0805KRX7R9BB104` (`C49678`) / footprint `CC0805KRX7R9BB104`. Reason: matched footprint differs.
- `C42`: schematic `0.1uF 50V` / MPN `—` / footprint `C_0805_2012Metric` → JLC match `CC0805KRX7R9BB104` (`C49678`) / footprint `CC0805KRX7R9BB104`. Reason: matched footprint differs.
- `C43`: schematic `0.1uF 50V` / MPN `—` / footprint `C_0805_2012Metric` → JLC match `CC0805KRX7R9BB104` (`C49678`) / footprint `CC0805KRX7R9BB104`. Reason: matched footprint differs.
- `C44`: schematic `1uF 50V` / MPN `—` / footprint `C_0805_2012Metric` → JLC match `CL21B105KBFNNNE` (`C28323`) / footprint `CC0805KRX7R9BB104`. Reason: matched footprint differs.
- `C5`: schematic `100nF 50V` / MPN `CC0805KRX7R9BB104` / footprint `C_0805_2012Metric` → JLC match `CC0805KRX7R9BB104` (`C49678`) / footprint `fp_71505040a9`. Reason: matched footprint differs.
- `C6`: schematic `8pF 50V` / MPN `CC0603JRNPO9BN8R0` / footprint `C_0603_1608Metric` → JLC match `0603CG8R0C500NT` (`C36508`) / footprint `CC0603JRNPO9BN8R0`. Reason: matched part differs; matched footprint differs.
- `C7`: schematic `8pF 50V` / MPN `CC0603JRNPO9BN8R0` / footprint `C_0603_1608Metric` → JLC match `0603CG8R0C500NT` (`C36508`) / footprint `CC0603JRNPO9BN8R0`. Reason: matched part differs; matched footprint differs.
- `C8`: schematic `0.1uF 50V` / MPN `—` / footprint `C_0805_2012Metric` → JLC match `CC0805KRX7R9BB104` (`C49678`) / footprint `CC0805KRX7R9BB104`. Reason: matched footprint differs.
- `C9`: schematic `10uF 50V` / MPN `GCM31CC71E106KA03L` / footprint `C1206` → JLC match `CL31A106KBHNNNE` (`C13585`) / footprint `C1206`. Reason: matched part differs.
- `J1`: schematic `RPI_5_WITH_SSQ-120-01-F-D` / MPN `SSQ-120-01-F-D` / footprint `SSM-120-XXX-DV` → JLC match `SSM-120-F-DV` (`C3323521`) / footprint `SSM-120-XXX-DV`. Reason: matched part differs.
- `J11`: schematic `M9N-G4-3100` / MPN `SSQ-104-01-L-D` / footprint `M9N-G4-3100` → JLC match `0805W8J0104T5E` (`C25611`) / footprint `M9N-G4-3100`. Reason: matched part differs.
- `J37`: schematic `B04B-JWPF-SK-R` / MPN `1778719` / footprint `B04B-JWPF-SK-R` → JLC match `B04B-JWPF-SK-R(LF)(SN)` (`C2983882`) / footprint `B04B-JWPF-SK-R`. Reason: matched part differs.
- `J38`: schematic `B04B-JWPF-SK-R` / MPN `1778719` / footprint `B04B-JWPF-SK-R` → JLC match `B04B-JWPF-SK-R(LF)(SN)` (`C2983882`) / footprint `B04B-JWPF-SK-R`. Reason: matched part differs.
- `J39`: schematic `B04B-JWPF-SK-R` / MPN `1814935` / footprint `B04B-JWPF-SK-R` → JLC match `B04B-JWPF-SK-R(LF)(SN)` (`C2983882`) / footprint `B04B-JWPF-SK-R`. Reason: matched part differs.
- `J43`: schematic `B04B-JWPF-SK-R` / MPN `SM04B-GHS-TB(LF)(SN)` / footprint `B04B-JWPF-SK-R` → JLC match `B04B-JWPF-SK-R(LF)(SN)` (`C2983882`) / footprint `B04B-JWPF-SK-R`. Reason: matched part differs.
- `J46`: schematic `B04B-JWPF-SK-R` / MPN `SM04B-GHS-TB(LF)(SN)` / footprint `B04B-JWPF-SK-R` → JLC match `B04B-JWPF-SK-R(LF)(SN)` (`C2983882`) / footprint `B04B-JWPF-SK-R`. Reason: matched part differs.
- `J48`: schematic `B04B-JWPF-SK-R` / MPN `SM04B-GHS-TB(LF)(SN)` / footprint `B04B-JWPF-SK-R` → JLC match `B04B-JWPF-SK-R(LF)(SN)` (`C2983882`) / footprint `B04B-JWPF-SK-R`. Reason: matched part differs.
- `J49`: schematic `B04B-JWPF-SK-R` / MPN `1814935` / footprint `B04B-JWPF-SK-R` → JLC match `B04B-JWPF-SK-R(LF)(SN)` (`C2983882`) / footprint `B04B-JWPF-SK-R`. Reason: matched part differs.
- `J56`: schematic `B04B-JWPF-SK-R` / MPN `SM04B-GHS-TB(LF)(SN)` / footprint `B04B-JWPF-SK-R` → JLC match `B04B-JWPF-SK-R(LF)(SN)` (`C2983882`) / footprint `B04B-JWPF-SK-R`. Reason: matched part differs.
- `J8`: schematic `B04B-JWPF-SK-R` / MPN `1814935` / footprint `B04B-JWPF-SK-R` → JLC match `B04B-JWPF-SK-R(LF)(SN)` (`C2983882`) / footprint `B04B-JWPF-SK-R`. Reason: matched part differs.
- `K1`: schematic `CPC1019N` / MPN `CPC1019N` / footprint `SOP254P610X218-4N` → JLC match `CPC1019NTR` (`C1854946`) / footprint `SOP254P610X218-4N`. Reason: matched part differs.
- `K10`: schematic `CPC1019N` / MPN `CPC1019N` / footprint `SOP254P610X218-4N` → JLC match `CPC1019NTR` (`C1854946`) / footprint `SOP254P610X218-4N`. Reason: matched part differs.
- `K2`: schematic `CPC1019N` / MPN `CPC1019N` / footprint `SOP254P610X218-4N` → JLC match `CPC1019NTR` (`C1854946`) / footprint `SOP254P610X218-4N`. Reason: matched part differs.
- `K4`: schematic `CPC1019N` / MPN `CPC1019N` / footprint `SOP254P610X218-4N` → JLC match `CPC1019NTR` (`C1854946`) / footprint `SOP254P610X218-4N`. Reason: matched part differs.
- `K5`: schematic `CPC1019N` / MPN `CPC1019N` / footprint `SOP254P610X218-4N` → JLC match `CPC1019NTR` (`C1854946`) / footprint `SOP254P610X218-4N`. Reason: matched part differs.
- `K6`: schematic `CPC1019N` / MPN `CPC1019N` / footprint `SOP254P610X218-4N` → JLC match `CPC1019NTR` (`C1854946`) / footprint `SOP254P610X218-4N`. Reason: matched part differs.
- `K7`: schematic `CPC1019N` / MPN `CPC1019N` / footprint `SOP254P610X218-4N` → JLC match `CPC1019NTR` (`C1854946`) / footprint `SOP254P610X218-4N`. Reason: matched part differs.
- `K8`: schematic `CPC1019N` / MPN `CPC1019N` / footprint `SOP254P610X218-4N` → JLC match `CPC1019NTR` (`C1854946`) / footprint `SOP254P610X218-4N`. Reason: matched part differs.
- `K9`: schematic `CPC1019N` / MPN `CPC1019N` / footprint `SOP254P610X218-4N` → JLC match `CPC1019NTR` (`C1854946`) / footprint `SOP254P610X218-4N`. Reason: matched part differs.
- `LED1`: schematic `RED` / MPN `LS T676-Q1R2-1-Z` / footprint `LEDC2012X85N` → JLC match `APT2012SURCK` (`C5875730`) / footprint `LEDC2012X85N`. Reason: matched part differs.
- `LED10`: schematic `RED` / MPN `LS T676-Q1R2-1-Z` / footprint `LEDC2012X85N` → JLC match `APT2012SURCK` (`C5875730`) / footprint `LEDC2012X85N`. Reason: matched part differs.
- `LED11`: schematic `RED` / MPN `LS T676-Q1R2-1-Z` / footprint `LEDC2012X85N` → JLC match `APT2012SURCK` (`C5875730`) / footprint `LEDC2012X85N`. Reason: matched part differs.
- `LED12`: schematic `RED` / MPN `LS T676-Q1R2-1-Z` / footprint `LEDC2012X85N` → JLC match `APT2012SURCK` (`C5875730`) / footprint `LEDC2012X85N`. Reason: matched part differs.
- `LED13`: schematic `RED` / MPN `LS T676-Q1R2-1-Z` / footprint `LEDC2012X85N` → JLC match `APT2012SURCK` (`C5875730`) / footprint `LEDC2012X85N`. Reason: matched part differs.
- `LED14`: schematic `RED` / MPN `LS T676-Q1R2-1-Z` / footprint `LEDC2012X85N` → JLC match `APT2012SURCK` (`C5875730`) / footprint `LEDC2012X85N`. Reason: matched part differs.
- `LED15`: schematic `RED` / MPN `LS T676-Q1R2-1-Z` / footprint `LEDC2012X85N` → JLC match `APT2012SURCK` (`C5875730`) / footprint `LEDC2012X85N`. Reason: matched part differs.
- `LED2`: schematic `RED` / MPN `LS T676-Q1R2-1-Z` / footprint `LEDC2012X85N` → JLC match `APT2012SURCK` (`C5875730`) / footprint `LEDC2012X85N`. Reason: matched part differs.
- `LED3`: schematic `RED` / MPN `LS T676-Q1R2-1-Z` / footprint `LEDC2012X85N` → JLC match `APT2012SURCK` (`C5875730`) / footprint `LEDC2012X85N`. Reason: matched part differs.
- `LED7`: schematic `RED` / MPN `LS T676-Q1R2-1-Z` / footprint `LEDC2012X85N` → JLC match `APT2012SURCK` (`C5875730`) / footprint `LEDC2012X85N`. Reason: matched part differs.
- `LED8`: schematic `RED` / MPN `LS T676-Q1R2-1-Z` / footprint `LEDC2012X85N` → JLC match `APT2012SURCK` (`C5875730`) / footprint `LEDC2012X85N`. Reason: matched part differs.
- `LED9`: schematic `RED` / MPN `LS T676-Q1R2-1-Z` / footprint `LEDC2012X85N` → JLC match `APT2012SURCK` (`C5875730`) / footprint `LEDC2012X85N`. Reason: matched part differs.
- `R1`: schematic `1K5 150V` / MPN `—` / footprint `R_0805_2012Metric` → JLC match `0805W8F1501T5E` (`C4310`) / footprint `fp_9fb50b8536`. Reason: matched footprint differs.
- `R10`: schematic `10k 150V` / MPN `RC0805FR-0710KL` / footprint `R_0805_2012Metric` → JLC match `0805W8F1002T5E` (`C17414`) / footprint `RC0805FR-0710KL`. Reason: matched part differs; matched footprint differs.
- `R11`: schematic `10k 150V` / MPN `RC0805FR-0710KL` / footprint `R_0805_2012Metric` → JLC match `0805W8F1002T5E` (`C17414`) / footprint `RC0805FR-0710KL`. Reason: matched part differs; matched footprint differs.
- `R12`: schematic `5K1 150V` / MPN `—` / footprint `R_0805_2012Metric` → JLC match `0805W8F5101T5E` (`C27834`) / footprint `fp_9fb50b8536`. Reason: matched footprint differs.
- `R13`: schematic `5K1 150V` / MPN `—` / footprint `R_0805_2012Metric` → JLC match `0805W8F5101T5E` (`C27834`) / footprint `fp_9fb50b8536`. Reason: matched footprint differs.
- `R14`: schematic `120R 150V` / MPN `RC0805FR-07120RL` / footprint `R_0805_2012Metric` → JLC match `0805W8F1200T5E` (`C17437`) / footprint `RC0805FR-07120RL`. Reason: matched part differs; matched footprint differs.
- `R16`: schematic `0R 150V` / MPN `RC0805FR-070RL` / footprint `R_0805_2012Metric` → JLC match `0805W8F0000T5E` (`C17477`) / footprint `RC0805FR-070RL`. Reason: matched part differs; matched footprint differs.
- `R17`: schematic `10K 150V` / MPN `RC0805FR-0710KL` / footprint `R_0805_2012Metric` → JLC match `0805W8F1002T5E` (`C17414`) / footprint `RC0805FR-0710KL`. Reason: matched part differs; matched footprint differs.
- `R18`: schematic `120R 150V` / MPN `RC0805FR-07120RL` / footprint `R_0805_2012Metric` → JLC match `0805W8F1200T5E` (`C17437`) / footprint `RC0805FR-07120RL`. Reason: matched part differs; matched footprint differs.
- `R19`: schematic `10K 150V` / MPN `RC0805FR-0710KL` / footprint `R_0805_2012Metric` → JLC match `0805W8F1002T5E` (`C17414`) / footprint `RC0805FR-0710KL`. Reason: matched part differs; matched footprint differs.
- `R2`: schematic `100k 150V` / MPN `—` / footprint `R_0805_2012Metric` → JLC match `0805W8J0104T5E` (`C25611`) / footprint `fp_9fb50b8536`. Reason: matched footprint differs.
- `R20`: schematic `10K 150V` / MPN `RC0805FR-0710KL` / footprint `R_0805_2012Metric` → JLC match `0805W8F1002T5E` (`C17414`) / footprint `RC0805FR-0710KL`. Reason: matched part differs; matched footprint differs.
- `R21`: schematic `10K 150V` / MPN `RC0805FR-0710KL` / footprint `R_0805_2012Metric` → JLC match `0805W8F1002T5E` (`C17414`) / footprint `RC0805FR-0710KL`. Reason: matched part differs; matched footprint differs.
- `R22`: schematic `1K5 150V` / MPN `—` / footprint `R_0805_2012Metric` → JLC match `0805W8F1501T5E` (`C4310`) / footprint `fp_9fb50b8536`. Reason: matched footprint differs.
- `R23`: schematic `100K 150V` / MPN `—` / footprint `R_0805_2012Metric` → JLC match `0805W8J0104T5E` (`C25611`) / footprint `fp_9fb50b8536`. Reason: matched footprint differs.
- `R24`: schematic `75K 150V` / MPN `—` / footprint `R_0805_2012Metric` → JLC match `0805W8F7502T5E` (`C17819`) / footprint `fp_9fb50b8536`. Reason: matched footprint differs.
- `R25`: schematic `10K 150V` / MPN `—` / footprint `R_0805_2012Metric` → JLC match `0805W8F1002T5E` (`C17414`) / footprint `fp_9fb50b8536`. Reason: matched footprint differs.
- `R26`: schematic `1K5 150V` / MPN `—` / footprint `R_0805_2012Metric` → JLC match `0805W8F1501T5E` (`C4310`) / footprint `fp_9fb50b8536`. Reason: matched footprint differs.
- `R27`: schematic `1K5 150V` / MPN `—` / footprint `R_0805_2012Metric` → JLC match `0805W8F1501T5E` (`C4310`) / footprint `fp_9fb50b8536`. Reason: matched footprint differs.
- `R28`: schematic `1R 150V` / MPN `—` / footprint `R_0805_2012Metric` → JLC match `0805W8F100KT5E` (`C25271`) / footprint `fp_9fb50b8536`. Reason: matched footprint differs.
- `R29`: schematic `4K7 150V` / MPN `—` / footprint `R_0805_2012Metric` → JLC match `0805W8F4701T5E` (`C17673`) / footprint `fp_9fb50b8536`. Reason: matched footprint differs.
- `R3`: schematic `100R 150V` / MPN `—` / footprint `R_0805_2012Metric` → JLC match `0805W8F1000T5E` (`C17408`) / footprint `fp_9fb50b8536`. Reason: matched footprint differs.
- `R30`: schematic `4K7 150V` / MPN `—` / footprint `R_0805_2012Metric` → JLC match `0805W8F4701T5E` (`C17673`) / footprint `fp_9fb50b8536`. Reason: matched footprint differs.
- `R31`: schematic `1R 150V` / MPN `—` / footprint `R_0805_2012Metric` → JLC match `0805W8F100KT5E` (`C25271`) / footprint `fp_9fb50b8536`. Reason: matched footprint differs.
- `R32`: schematic `1R 150V` / MPN `—` / footprint `R_0805_2012Metric` → JLC match `0805W8F100KT5E` (`C25271`) / footprint `fp_9fb50b8536`. Reason: matched footprint differs.
- `R33`: schematic `100K 150V` / MPN `—` / footprint `R_0805_2012Metric` → JLC match `0805W8J0104T5E` (`C25611`) / footprint `fp_9fb50b8536`. Reason: matched footprint differs.
- `R34`: schematic `75K 150V` / MPN `—` / footprint `R_0805_2012Metric` → JLC match `0805W8F7502T5E` (`C17819`) / footprint `fp_9fb50b8536`. Reason: matched footprint differs.
- `R35`: schematic `10K 150V` / MPN `—` / footprint `R_0805_2012Metric` → JLC match `0805W8F1002T5E` (`C17414`) / footprint `fp_9fb50b8536`. Reason: matched footprint differs.
- `R36`: schematic `100K 150V` / MPN `—` / footprint `R_0805_2012Metric` → JLC match `0805W8J0104T5E` (`C25611`) / footprint `fp_9fb50b8536`. Reason: matched footprint differs.
- `R37`: schematic `75K 150V` / MPN `—` / footprint `R_0805_2012Metric` → JLC match `0805W8F7502T5E` (`C17819`) / footprint `fp_9fb50b8536`. Reason: matched footprint differs.
- `R38`: schematic `10K 150V` / MPN `—` / footprint `R_0805_2012Metric` → JLC match `0805W8F1002T5E` (`C17414`) / footprint `fp_9fb50b8536`. Reason: matched footprint differs.
- `R39`: schematic `1R 150V` / MPN `—` / footprint `R_0805_2012Metric` → JLC match `0805W8F100KT5E` (`C25271`) / footprint `fp_9fb50b8536`. Reason: matched footprint differs.
- `R4`: schematic `100k 150V` / MPN `—` / footprint `R_0805_2012Metric` → JLC match `0805W8J0104T5E` (`C25611`) / footprint `fp_9fb50b8536`. Reason: matched footprint differs.
- `R40`: schematic `1R 150V` / MPN `—` / footprint `R_0805_2012Metric` → JLC match `0805W8F100KT5E` (`C25271`) / footprint `fp_9fb50b8536`. Reason: matched footprint differs.
- `R41`: schematic `1R 150V` / MPN `—` / footprint `R_0805_2012Metric` → JLC match `0805W8F100KT5E` (`C25271`) / footprint `fp_9fb50b8536`. Reason: matched footprint differs.
- `R42`: schematic `1K5 150V` / MPN `—` / footprint `R_0805_2012Metric` → JLC match `0805W8F1501T5E` (`C4310`) / footprint `fp_9fb50b8536`. Reason: matched footprint differs.
- `R43`: schematic `1K5 150V` / MPN `—` / footprint `R_0805_2012Metric` → JLC match `0805W8F1501T5E` (`C4310`) / footprint `fp_9fb50b8536`. Reason: matched footprint differs.
- `R44`: schematic `1K5 150V` / MPN `—` / footprint `R_0805_2012Metric` → JLC match `0805W8F1501T5E` (`C4310`) / footprint `fp_9fb50b8536`. Reason: matched footprint differs.
- `R45`: schematic `1K5 150V` / MPN `—` / footprint `R_0805_2012Metric` → JLC match `0805W8F1501T5E` (`C4310`) / footprint `fp_9fb50b8536`. Reason: matched footprint differs.
- `R46`: schematic `1K5 150V` / MPN `—` / footprint `R_0805_2012Metric` → JLC match `0805W8F1501T5E` (`C4310`) / footprint `fp_9fb50b8536`. Reason: matched footprint differs.
- `R47`: schematic `47K 150V` / MPN `—` / footprint `R_0805_2012Metric` → JLC match `0805W8F4702T5E` (`C17713`) / footprint `fp_9fb50b8536`. Reason: matched footprint differs.
- `R48`: schematic `47K 150V` / MPN `—` / footprint `R_0805_2012Metric` → JLC match `0805W8F4702T5E` (`C17713`) / footprint `fp_9fb50b8536`. Reason: matched footprint differs.
- `R49`: schematic `47K 150V` / MPN `—` / footprint `R_0805_2012Metric` → JLC match `0805W8F4702T5E` (`C17713`) / footprint `fp_9fb50b8536`. Reason: matched footprint differs.
- `R5`: schematic `100k 150V` / MPN `—` / footprint `R_0805_2012Metric` → JLC match `0805W8J0104T5E` (`C25611`) / footprint `fp_9fb50b8536`. Reason: matched footprint differs.
- `R50`: schematic `2K 150V` / MPN `RC0805FR-072KL` / footprint `R_0805_2012Metric` → JLC match `0805W8F2001T5E` (`C17604`) / footprint `RC0805FR-072KL`. Reason: matched part differs; matched footprint differs.
- `R51`: schematic `2K 150V` / MPN `RC0805FR-072KL` / footprint `R_0805_2012Metric` → JLC match `0805W8F2001T5E` (`C17604`) / footprint `RC0805FR-072KL`. Reason: matched part differs; matched footprint differs.
- `R52`: schematic `2K 150V` / MPN `RC0805FR-072KL` / footprint `R_0805_2012Metric` → JLC match `0805W8F2001T5E` (`C17604`) / footprint `RC0805FR-072KL`. Reason: matched part differs; matched footprint differs.
- `R53`: schematic `2K 150V` / MPN `RC0805FR-072KL` / footprint `R_0805_2012Metric` → JLC match `0805W8F2001T5E` (`C17604`) / footprint `RC0805FR-072KL`. Reason: matched part differs; matched footprint differs.
- `R54`: schematic `2K 150V` / MPN `RC0805FR-072KL` / footprint `R_0805_2012Metric` → JLC match `0805W8F2001T5E` (`C17604`) / footprint `RC0805FR-072KL`. Reason: matched part differs; matched footprint differs.
- `R55`: schematic `2K 150V` / MPN `RC0805FR-072KL` / footprint `R_0805_2012Metric` → JLC match `0805W8F2001T5E` (`C17604`) / footprint `RC0805FR-072KL`. Reason: matched part differs; matched footprint differs.
- `R56`: schematic `47K 150V` / MPN `—` / footprint `R_0805_2012Metric` → JLC match `0805W8F4702T5E` (`C17713`) / footprint `fp_9fb50b8536`. Reason: matched footprint differs.
- `R57`: schematic `47K 150V` / MPN `—` / footprint `R_0805_2012Metric` → JLC match `0805W8F4702T5E` (`C17713`) / footprint `fp_9fb50b8536`. Reason: matched footprint differs.
- `R58`: schematic `47K 150V` / MPN `—` / footprint `R_0805_2012Metric` → JLC match `0805W8F4702T5E` (`C17713`) / footprint `fp_9fb50b8536`. Reason: matched footprint differs.
- `R59`: schematic `47K 150V` / MPN `—` / footprint `R_0805_2012Metric` → JLC match `0805W8F4702T5E` (`C17713`) / footprint `fp_9fb50b8536`. Reason: matched footprint differs.
- `R6`: schematic `100R 150V` / MPN `—` / footprint `R_0805_2012Metric` → JLC match `0805W8F1000T5E` (`C17408`) / footprint `fp_9fb50b8536`. Reason: matched footprint differs.
- `R67`: schematic `2mR` / MPN `PA2512FKE070R002E` / footprint `R_2512_6332Metric` → JLC match `JER2512F3R002` (`C46634447`) / footprint `2512`. Reason: matched part differs.
- `R68`: schematic `2mR` / MPN `PA2512FKE070R002E` / footprint `R_2512_6332Metric` → JLC match `JER2512F3R002` (`C46634447`) / footprint `2512`. Reason: matched part differs.
- `R69`: schematic `2mR` / MPN `PA2512FKE070R002E` / footprint `R_2512_6332Metric` → JLC match `JER2512F3R002` (`C46634447`) / footprint `2512`. Reason: matched part differs.
- `R7`: schematic `10K 150V` / MPN `—` / footprint `R_0805_2012Metric` → JLC match `0805W8F1002T5E` (`C17414`) / footprint `fp_9fb50b8536`. Reason: matched footprint differs.
- `R70`: schematic `2mR` / MPN `PA2512FKE070R002E` / footprint `R_2512_6332Metric` → JLC match `JER2512F3R002` (`C46634447`) / footprint `2512`. Reason: matched part differs.
- `R71`: schematic `2mR` / MPN `PA2512FKE070R002E` / footprint `R_2512_6332Metric` → JLC match `JER2512F3R002` (`C46634447`) / footprint `2512`. Reason: matched part differs.
- `R72`: schematic `2mR` / MPN `PA2512FKE070R002E` / footprint `R_2512_6332Metric` → JLC match `JER2512F3R002` (`C46634447`) / footprint `2512`. Reason: matched part differs.
- `R74`: schematic `2K 150V` / MPN `RC0805FR-072KL` / footprint `R_0805_2012Metric` → JLC match `0805W8F2001T5E` (`C17604`) / footprint `RC0805FR-072KL`. Reason: matched part differs; matched footprint differs.
- `R75`: schematic `2K 150V` / MPN `RC0805FR-072KL` / footprint `R_0805_2012Metric` → JLC match `0805W8F2001T5E` (`C17604`) / footprint `RC0805FR-072KL`. Reason: matched part differs; matched footprint differs.
- `R76`: schematic `2K 150V` / MPN `RC0805FR-072KL` / footprint `R_0805_2012Metric` → JLC match `0805W8F2001T5E` (`C17604`) / footprint `RC0805FR-072KL`. Reason: matched part differs; matched footprint differs.
- `R77`: schematic `560R 150V` / MPN `—` / footprint `R_0805_2012Metric` → JLC match `0805W8J0561T5E` (`C25319`) / footprint `fp_9fb50b8536`. Reason: matched footprint differs.
- `R78`: schematic `560R 150V` / MPN `—` / footprint `R_0805_2012Metric` → JLC match `0805W8J0561T5E` (`C25319`) / footprint `fp_9fb50b8536`. Reason: matched footprint differs.
- `R79`: schematic `560R 150V` / MPN `—` / footprint `R_0805_2012Metric` → JLC match `0805W8J0561T5E` (`C25319`) / footprint `fp_9fb50b8536`. Reason: matched footprint differs.
- `R8`: schematic `100k 150V` / MPN `RC0805FR-0710KL` / footprint `R_0805_2012Metric` → JLC match `0805W8F1003T5E` (`C149504`) / footprint `RC0805FR-0710KL`. Reason: matched part differs; matched footprint differs.
- `R9`: schematic `10K 150V` / MPN `—` / footprint `R_0805_2012Metric` → JLC match `0805W8F1002T5E` (`C17414`) / footprint `fp_9fb50b8536`. Reason: matched footprint differs.
- `U13`: schematic `SMTWEM245STR` / MPN `SMTWEM245STR` / footprint `SCREW-SMD_BD4.4-D2.8-H4.5` → JLC match `TH162050CTJ` (`C3020130`) / footprint `SCREW-SMD_BD4.4-D2.8-H4.5`. Reason: matched part differs.
- `U14`: schematic `SMTWEM245STR` / MPN `SMTWEM245STR` / footprint `SCREW-SMD_BD4.4-D2.8-H4.5` → JLC match `TH162050CTJ` (`C3020130`) / footprint `SCREW-SMD_BD4.4-D2.8-H4.5`. Reason: matched part differs.
- `U15`: schematic `SMTWEM245STR` / MPN `SMTWEM245STR` / footprint `SCREW-SMD_BD4.4-D2.8-H4.5` → JLC match `TH162050CTJ` (`C3020130`) / footprint `SCREW-SMD_BD4.4-D2.8-H4.5`. Reason: matched part differs.
- `U16`: schematic `SMTWEM245STR` / MPN `SMTWEM245STR` / footprint `SCREW-SMD_BD4.4-D2.8-H4.5` → JLC match `TH162050CTJ` (`C3020130`) / footprint `SCREW-SMD_BD4.4-D2.8-H4.5`. Reason: matched part differs.
- `U2`: schematic `MCP2515-I/SO` / MPN `MCP2515-I/SO` / footprint `SOIC127P1030X265-18N` → JLC match `MCP2515T-I/SO` (`C153782`) / footprint `SOIC127P1030X265-18N`. Reason: matched part differs.
- `U29`: schematic `LTC4370IMS#PBF` / MPN `LTC4370IMS#PBF` / footprint `MSOP-16_3x4.039mm_P0.5mm` → JLC match `LTC4370IDE#PBF` (`C580892`) / footprint `MSOP-16_3x4.039mm_P0.5mm`. Reason: matched part differs.
- `U30`: schematic `LTC4370IMS#PBF` / MPN `LTC4370IMS#PBF` / footprint `MSOP-16_3x4.039mm_P0.5mm` → JLC match `LTC4370IDE#PBF` (`C580892`) / footprint `MSOP-16_3x4.039mm_P0.5mm`. Reason: matched part differs.
- `U31`: schematic `LTC4370IMS#PBF` / MPN `LTC4370IMS#PBF` / footprint `MSOP-16_3x4.039mm_P0.5mm` → JLC match `LTC4370IDE#PBF` (`C580892`) / footprint `MSOP-16_3x4.039mm_P0.5mm`. Reason: matched part differs.
- `X1`: schematic `16MHz` / MPN `NX3225GB-16M-STD-CRA-2` / footprint `NX3225GB-16M-STD-CRA-2` → JLC match `NX3225GB-16MHZ-STD-CRA-2` (`C481399`) / footprint `NX3225GB-16M-STD-CRA-2`. Reason: matched part differs.

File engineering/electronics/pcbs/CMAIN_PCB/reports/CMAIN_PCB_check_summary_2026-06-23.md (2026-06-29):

# CMAIN PCB KiCad check summary — 2026-06-23

Input archive: Julius Discord upload `CMAIN_PCB.7z` from 2026-06-23.

Cleanup performed:

- Integrated the updated CMAIN KiCad files and native project-local footprints from the archive.
- Removed the `EasyEDA_Lib_CMAIN` EasyEDA/JLCEDA Pro plugin library entry and loader artifact so KiCad only needs project-local native KiCad libraries plus standard KiCad libraries.
- Moved the new TH162050CTJ standoff symbol/footprint into the project-local `CMAIN_PCB` KiCad library namespace.
- Remapped undefined `Rescue` layer references to `F.Fab` in the board/footprint source files.
- Excluded KiCad `.history` and `CMAIN_PCB-backups` archive files from import.

Verification with KiCad CLI 10.0.1:

- `kicad-cli sch erc --format json engineering/electronics/pcbs/CMAIN_PCB/kicad/CMAIN_PCB.kicad_sch`
  - 16 ERC violations remain, all `pin_to_pin` warnings from unspecified-pin imported symbols.
  - 0 `lib_symbol_issues` remain.
- `kicad-cli pcb drc --format json engineering/electronics/pcbs/CMAIN_PCB/kicad/CMAIN_PCB.kicad_pcb`
  - 96 DRC violations remain: 53 `silk_overlap`, 41 `silk_over_copper`, 1 `lib_footprint_mismatch`, 1 `text_thickness`.
  - 0 unconnected items.

No live `Rescue` or `EasyEDA_Lib_CMAIN` references remain in the KiCad project files after cleanup.

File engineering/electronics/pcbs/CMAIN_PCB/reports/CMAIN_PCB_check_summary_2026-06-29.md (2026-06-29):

# CMAIN PCB KiCad check summary - 2026-06-29

Input archive: Julius Discord upload `CMAIN_PCB_2906.7z` from 2026-06-29.

Update integrated:

- Imported the latest CMAIN KiCad schematic, PCB layout, project-local symbols/footprints, 3D model updates, and STEP export.
- Added the rounded-tracks config file from the archive.
- Added prototype-ordering output under `kicad/production/`.
- Excluded KiCad `.history`, `CMAIN_PCB-backups`, lockfiles, `.bak` files, and local `jlcpcb/` cache files from the repo import.
- Left the EasyEDA/JLCEDA Pro loader artifact out of the repo; the KiCad project still uses native project-local KiCad symbol and footprint libraries.

Verification with KiCad CLI 10.0.1:

- `kicad-cli sch erc --format json engineering/electronics/pcbs/CMAIN_PCB/kicad/CMAIN_PCB.kicad_sch`
  - 0 ERC violations remain.
  - 0 `lib_symbol_issues` remain.
- `kicad-cli pcb drc --format json engineering/electronics/pcbs/CMAIN_PCB/kicad/CMAIN_PCB.kicad_pcb`
  - 2 DRC violations remain:
    - 1 `silk_edge_clearance`: the back-silkscreen warning text touches/clips the board edge clearance.
    - 1 `lib_footprint_mismatch`: `D8` footprint `SMA_L4.3-W2.6-LS5.0-FD` differs from the copy in library `EasyEDA_Lib`.
  - 0 unconnected items.

Local validation note: KiCad reported local font substitution for `Karla` during DRC (`Skia Bold` used locally).

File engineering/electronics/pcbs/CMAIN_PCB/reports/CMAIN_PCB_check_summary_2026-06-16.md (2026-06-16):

# CMAIN PCB KiCad Check Summary — 2026-06-16

Imported from Julius’s latest CMAIN KiCad update archive posted in Discord on 2026-06-16.

## Import cleanup

- Excluded local KiCad `.history/` and `CMAIN_PCB-backups/` directories from the repo import.
- Remapped undefined footprint graphics layer `Rescue` to `F.Fab` in `CMAIN_PCB.kicad_pcb` and `libs/EasyEDA_Lib.pretty/SMD_SMTSO3060CTJ.kicad_mod`.
- No `Rescue` layer references remain in the CMAIN KiCad project files.

## KiCad CLI checks

- Tool: KiCad CLI 10.0.1
- Schematic ERC: **0 violations**
- PCB DRC: **7 violations**, **0 unconnected items**

### DRC violation buckets

- lib_footprint_mismatch: 6
- text_thickness: 1

Raw JSON reports are saved next to this summary.

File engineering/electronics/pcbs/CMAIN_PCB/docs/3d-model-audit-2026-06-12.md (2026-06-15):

# CMAIN 3D model audit — 2026-06-12

Audit scope: model references in `kicad/CMAIN_PCB.kicad_pcb` and local CMAIN footprint libraries.

## Result

- Total model references: 344
- Resolved after cleanup: 307
- Still unresolved: 37 references / 13 unique model paths

## Fixed in this pass

- Updated stale KiCad 8 `.wrl` passive-component refs to KiCad 10 `.step` models:
  - `R_0805_2012Metric`
  - `C_0805_2012Metric`
  - `C_0603_1608Metric`
- Updated the JLCPCB `D_SMB.step` ref to KiCad's built-in `Diode_SMD.3dshapes/D_SMB.step`.
- Updated relative `NX3225GB-16M-STD-CRA-2.stp` refs to KiCad's built-in `Crystal_SMD_3225-4Pin_3.2x2.5mm.step`.
- Added reusable models already present elsewhere in the Caribou repo:
  - `EASYEDA_MODELS/C1206_L3.2-W1.6-H1.3.step`
  - `EASYEDA_MODELS/SMB_L4.6-W3.6-LS5.3-RD.step`
  - `EASYEDA_MODELS/SMC_L7.1-W6.2-LS8.1-RD.step`
  - `ALTIUM_EMBEDDED_MODELS/AT13-08PA-BM01.stp`
- Tried `dsa-t/jlc-kicad-lib-loader` against the CMAIN LCSC codes. The plugin is runnable, but EasyEDA's `searchByCodes` endpoint returned CloudFront `403 Request blocked` from this host.
- Used `JLC2KiCadLib` as a fallback against the same LCSC/JLC codes and copied the downloaded STEP models into `EASYEDA_MODELS/`.
- Replaced obvious standard-package missing refs with KiCad built-in equivalents:
  - 0805 LEDs
  - 0603/SOD-123 diodes
  - SOIC/SOP/QFN packages
  - JST-GH 4/5/6 pin connectors
  - generic screw/standoff bodies
  - Phoenix 2.5 mm 4/5/6-position terminal/header bodies
  - 8.5-9 mm magnetic buzzer body

## Local EasyEDA/JLC STEP models now present

- `C1206_L3.2-W1.6-H1.3.step`
- `CAP-SMD_L7.3-W4.3-RD_PA300LV227M0J.step`
- `CAP-TH_BD10.0-P5.00-D0.6-FD_2.step`
- `CAP-TH_D8.0-H8.0-P3.50.step`
- `CONN-SMD_GH1.25-LS-4P.step`
- `CONN-TH_5P-P2.50_ZX-XH2.54-5PZZ.step`
- `CONN-TH_SM03B-GHS-TB-LF-SN.step`
- `IND-SMD_CYA0650-3.3UH.step`
- `IND-SMD_L11.6-W10.1-H4.0.step`
- `POWERPAK-SO-8_L5.9-W4.9-P1.27-LS6.2-BL.step`
- `PWRM-TH_YLPTEC_URBXXXXS-6WR3.step`
- `R0402_L1.0-W0.5-H0.4.step`
- `SCREW-SMD_BD4.4-D2.8-H4.5.step`
- `SMA_L4.3-W2.6-LS5.0-FD.step`
- `SMB_L4.6-W3.6-LS5.3-RD.step`
- `SMC_L7.1-W6.2-LS8.1-RD.step`
- `SMD_BD5.6-L5.6-W5.6-D4.1.step`
- `SMD_SMTSO3060CTJ.step`
- `SOT-23-6_L2.9-W1.6-H1.5-LS2.8-P0.95.step`
- `USB-C-SMD_TYPEC-303-ACP16.step`

## Remaining unresolved model refs

These are the refs that still do not have a safe local/generic substitute. They are mostly connector/fuse/module parts where wrong geometry could hurt enclosure work more than no model.

```text
8   ${KICAD_3RD_PARTY}/Samacsys.3dshapes/0154001.DR.stp
4   ${KICAD_3RD_PARTY}/Snapeda.3dshapes/axk6s00547y.stp
3   ${KICAD_3RD_PARTY}/Samacsys.3dshapes/SLW-913535-2A-SMT.stp
3   ${KICAD_3RD_PARTY}/Snapeda.3dshapes/GIGABLOX_NANO_SWITCH_REVA_MODULE.step
3   ${KICAD_3RD_PARTY}/Samacsys.3dshapes/LSHM-120-02.5-L-DV-A-S-K-TR.stp
3   ${KICAD_3RD_PARTY}/Samacsys.3dshapes/SSM-120-F-DV.stp
3   ${KICAD_3RD_PARTY}/Snapeda.3dshapes/XT30PW-F.step
3   ${KICAD_3RD_PARTY}/Samacsys.3dshapes/1812L110_24DR.stp
2   ${KICAD_3RD_PARTY}/Samacsys.3dshapes/USB4215-03-A.stp
2   AT13-6P-BM03GRY.stp
1   ${KICAD_3RD_PARTY}/Samacsys.3dshapes/REC20K-4805SZ.stp
1   0154001.DR.stp
1   ${KICAD_3RD_PARTY}/Samacsys.3dshapes/REC30K-4812SZ.stp
```

Next step: add exact vendor STEP models for these remaining parts from SnapEDA/Samacsys/vendor downloads, or confirm an acceptable generic substitute for each connector/module.

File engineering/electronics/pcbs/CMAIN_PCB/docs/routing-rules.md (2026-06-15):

# CMAIN PCB routing rules

Generated for the KiCad 10 CMAIN layout cleanup on 2026-06-15, following the CBC PCB rule-normalization workflow.

## Scope

- Added project net classes and explicit net assignments for all named CMAIN board nets.
- Added standard track-width and via presets.
- Normalized existing routed segment widths and via sizes to their assigned net-class values.
- Did not intentionally move footprints, tracks, vias, zones, or board geometry.

## Net classes

- `Signal_Control`: 0.20 mm tracks, 0.60 / 0.30 mm vias, 0.20 mm clearance.
- `CAN_Bus`: 0.20 mm tracks, 0.60 / 0.30 mm vias, 0.20 mm clearance, 0.20 mm diff-pair width/gap.
- `Ethernet`: 0.20 mm tracks, 0.60 / 0.30 mm vias, 0.20 mm clearance, 0.20 mm diff-pair width/gap.
- `Power_0V5A`: 0.30 mm tracks, 0.60 / 0.30 mm vias, 0.20 mm clearance.
- `Power_1A`: 0.50 mm tracks, 0.80 / 0.40 mm vias, 0.25 mm clearance.
- `Power_5A`: 1.00 mm tracks, 1.20 / 0.60 mm vias, 0.30 mm clearance.
- `GND_System`: 0.30 mm tracks, 0.60 / 0.30 mm vias, 0.25 mm clearance.

## Assignment heuristics

- `GND` → `GND_System`.
- `CAN*` and `/CAN*` nets → `CAN_Bus`.
- `ETH*` and RJ45 `J47 P1*_P/N` pair nets → `Ethernet`.
- `12V_*`, `12VSW`, and `+12V_PL` → `Power_5A`.
- `5V_*`, `+3.3V`, `/IO_VDD_3V3`, `/VBUS`, and `*3V3*` nets → `Power_0V5A`.
- Remaining named nets → `Signal_Control`.

## Change summary

- Named nets assigned: 539.
- Routed segments seen: 1,648 total, 1,641 named.
- Segment widths normalized: 516.
- Vias seen: 203 named.
- Via sizes normalized: 14.
- Track/via geometry check: segment and via counts unchanged; start/end/layer/net/UUID content is unchanged when width, size, and drill fields are ignored.

## DRC snapshot

KiCad CLI command:

```bash
kicad-cli pcb drc engineering/electronics/pcbs/CMAIN_PCB/kicad/CMAIN_PCB.kicad_pcb --format json --output /tmp/cmain-drc-after-rules.json
```

Before rule/width normalization:

- 404 violations
- 391 unconnected items
- Top categories: 131 `silk_over_copper`, 71 `track_dangling`, 55 `silk_overlap`, 47 `via_dangling`, 29 `text_height`, 24 `copper_edge_clearance`

After rule/width normalization:

- 634 violations
- 391 unconnected items
- Top categories: 201 `clearance`, 131 `silk_over_copper`, 75 `silk_overlap`, 71 `track_dangling`, 46 `via_dangling`, 29 `text_height`, 24 `copper_edge_clearance`

The increased DRC count is expected from widening existing copper and enabling stricter clearance/silk/mask settings. No rerouting was done in this pass.

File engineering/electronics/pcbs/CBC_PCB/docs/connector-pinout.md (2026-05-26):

# CBC_PCB — Connector Pinout Reference

## 1. Battery Connector — Prolanv EN60A ↔ ACES 59604-0169D-003

The Prolanv EN60A (board side) mates with the ACES 59604-0169D-003 built into the Tattu 4.0 battery.

### Power Contacts

| Bank | Function | Pairs | Current per Pair | Total Capacity |
|---|---|---|---|---|
| Left (red) | Positive (+) | 5 | 60A | 300A |
| Right (blue) | Negative (−) | 5 | 60A | 300A |

### Signal Contacts

| Pin | Function | Notes |
|---|---|---|
| CAN H | Battery CAN High | → MCP2515 #1 (CAN 1) via SN65HVD230 |
| CAN L | Battery CAN Low | → MCP2515 #1 (CAN 1) via SN65HVD230 |
| PIN1 | Battery Present Detection | Must be shorted to PIN2 on EN60A side |
| PIN2 | Battery Present Detection | Must be shorted to PIN1 on EN60A side |
| (unused) | — | 2 signal pins reserved |

> ⚠️ **PIN1 + PIN2 must be bridged** on the EN60A (PCB trace or jumper). Without this bridge, the Tattu 4.0 battery will not power on.

## 2. Signal Connector — Amphenol AT13-12PB-BM03

12-position automotive-grade connector carrying regulated power and signals to the Caribou main harness → [CMAIN_PCB](../../CMAIN_PCB/).

### Proposed Pin Assignment

| Pin | Signal | Domain | Notes |
|---|---|---|---|
| 1 | 12V OUT | GNDE | Isolated 12V supply to aircraft; protect with a dedicated output fuse before harness output |
| 2 | 12V OUT | GNDE | Parallel pin for current sharing |
| 3 | GND_E | GNDE | Isolated ground return |
| 4 | GND_E | GNDE | Parallel pin for current sharing |
| 5 | DroneCAN H | CAN 2 / `GND_CB` reference | CAN 2 High → CMAIN_PCB |
| 6 | DroneCAN L | CAN 2 / `GND_CB` reference | CAN 2 Low → CMAIN_PCB |
| 7 | KILL_IN / `12V_TRIGGER_SIG` | Harness control | Hardware kill switch input |
| 8 | Reserved | — | Future use |
| 9 | Reserved | — | Future use |
| 10 | Reserved | — | Future use |
| 11 | Reserved | — | Future use |
| 12 | Reserved | — | Future use |

> **Note:** Pin assignment is preliminary and subject to change during schematic design. Dual pins for 12V and GND_E are used to share the 10A load across two AT contacts (each AT contact is rated ~7.5A for 14 AWG).
>
> **Ground-domain note:** The battery CAN connector normally carries only `CANH_BAT` and `CANL_BAT`; `GND_CA` is not normally connected to the battery. DroneCAN may carry/use `GND_CB` on the CMAIN_PCB side, where it can be tied together with the other CBC_PCB `GND_CB` references.
>
> **Termination note:** CAN termination is jumper-selectable and normally deactivated/open by default. Enable termination only when this board is at the physical end of the CAN segment.

## 3. Propulsion Screw Terminals — Amphenol AMT0650009DB0000G

Two 6-pin screw terminal blocks for high-current output to the Hobbywing XRotor X15.

| Terminal Block | Function | Cable | Termination |
|---|---|---|---|
| Block 1 | Positive (+) output | Red cable | Ring lug, M5 bolt |
| Block 2 | Negative (−) output | Black cable | Ring lug, M5 bolt |

Cable gauge: sized for 200A spike — check hobbywing wire gauge.

## 4. Fuse Mount — Eaton AMXL-250

The fuse is bolt-mounted between two additional AMT0650009DB0000G screw terminals on the board. In the schematic/layout these fuse terminals are J4/J5.

```
Battery (-) ──→ [Screw Terminal A] ──→ [AMXL-250 Fuse] ──→ [Screw Terminal B] ──→ MOSFET stage
```

| Parameter | Value |
|---|---|
| Fuse Rating | 250A |
| Voltage Rating | 125 Vdc |
| Bolt Size | M5 |

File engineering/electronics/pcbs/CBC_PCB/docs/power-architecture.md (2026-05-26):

# CBC_PCB — Power Architecture

## Overview

The CBC board handles two distinct power domains with galvanic isolation between them:

- **GNDI** (Ground Internal) — non-isolated, powers onboard logic only
- **GNDE** (Ground External) — isolated, powers the aircraft electrical system via CMAIN_PCB

This isolation ensures that faults on one power train system cannot propagate into the aircraft LV bus.

## Power Flow Diagram

```
                    Tattu 4.0 Battery (18S, 54–75.6V)
                              |
                     [Prolanv EN60A Connector]
                              |
                     [AMXL-250 Fuse, 250A]
                              |
                     [MOSFET Power Stage]
                      /               \
                     /                 \
            [Propulsion Output]     [HV Bus Tap]
            to X15 via screw         |          \
            terminals             [Buck]    [Push-Pull]
            (100A cont /          5V/1A     12V/10A
             200A spike)          (GNDI)    (GNDE, isolated)
                                    |           |
                                  [LDO]     [AT Signal
                                  3.3V      Connector]
                                  (GNDI)    → to CMAIN_PCB
                                    |
                              [ESP32-C3]
                              [MCP2515 ×2]
                              [SN65HVD230 ×2]
                              [Gate Drivers]
                              [Sensors]
```

## MOSFET Power Stage

The power stage uses N-channel MOSFETs in a high-side configuration with charge pump gate drivers. Three switching functions are implemented:

### 1. Precharge Switch
- **Purpose:** Limits inrush current when first connecting to the ESC input capacitors
- **Method:** Series resistor (e.g. 10–47 Ω, power-rated) + MOSFET bypass
- **Sequence:** Precharge MOSFET closes first → capacitors charge through resistor → main MOSFET closes → precharge MOSFET opens
- **Duration:** Typically 500 ms – 2 s (firmware-controlled)

### 2. Main Power Enable
- **Purpose:** Connects the HV bus to the propulsion output after precharge completes
- **Method:** Low-Rdson N-channel MOSFET(s) in parallel for current sharing
- **Rating:** Must handle 200A spike with acceptable Rdson heating

### 3. Kill Switch
- **Purpose:** Emergency power cutoff, independent of MCU state
- **Method:** Hardware latch — external KILL_IN / `12V_TRIGGER_SIG` signal (from AT connector pin 7), only kills the circuit after a short delay
- **Behavior:** Opens/removes the main MOSFET gate drive regardless of firmware state
- **Recovery:** Requires power cycle or explicit re-arm command
- **Default state:** `ESP_ENABLE_SIGNAL` is held low by `R16` (10k pulldown), so the ESP-controlled latch input is default-off during reset/boot.

## Voltage Regulation Details

### 5V Buck (GNDI)

| Parameter | Specification |
|---|---|
| Input Range | 54–75.6V |
| Output | 5.0V ± 5% |
| Output Current | ≥ 1A |
| Topology | Synchronous buck |
| Candidate IC | MP9487 or similar (100V+ Vin, integrated FETs) |
| Isolation | None (GNDI domain) |

The 5V rail is the main supply for all onboard logic. It must handle the full 18S voltage range and remain stable during transient load changes on the HV bus.

### 3.3V LDO (GNDI)

| Parameter | Specification |
|---|---|
| Input | 5.0V (from buck above) |
| Output | 3.3V ± 3% |
| Output Current | ≥ 500 mA |
| Topology | Linear regulator (LDO) |
| Candidate IC | AMS1117-3.3 or similar |
| Dropout | ≤ 1.0V |
| Power Dissipation | (5.0 − 3.3) × 0.5 = 0.85W max |

### 12V Isolated Supply (GNDE)

| Parameter | Specification |
|---|---|
| Input Range | 54–75.6V |
| Output | 12.0V ± 5% |
| Output Current | ≥ 10A |
| Topology | Isolated push-pull (or similar) |
| Isolation Voltage | ≥ 500V (functional isolation) |
| Candidate IC | TBD |

The 12V isolated output is the primary regulated power supply for the Caribou aircraft. It feeds through the AT signal connector into the wiring harness and on to the [CMAIN_PCB](../../CMAIN_PCB/), which distributes power to avionics, sensors, servos, and other subsystems.

Add a dedicated output fuse on `12V_ISOLATED` before the harness-facing output. The selected follow-up part is another `0154005.DR`, matching the existing small fuse family used elsewhere in the design.

At 12V / 10A = 120W output. With an assumed 90% converter efficiency:
- Input power = 120 / 0.90 = 133.33W
- Input current at 54V (worst case) = 133.33 / 54 = 2.4691A
- Input current at 75.6V = 133.33 / 75.6 = 1.7636A

## Pull-up / Strap Notes

- `GPIO0` is an ESP32 boot strap pin. Keep it high during normal boot. Add or reserve an external pull-up option to `+3V3` so USB-UART/autoprogramming circuitry cannot leave the board in download mode accidentally.
- `CS#1` and `CS#2` should have pull-ups to keep both MCP2515 controllers deselected while the ESP32 is reset, booting, or tri-stated.
- `INT#1` and `INT#2` may rely on ESP32 internal pull-ups if the MCP2515 interrupt outputs are configured/verified as open-drain-style active-low outputs in firmware. If bring-up shows noisy interrupts, add external pull-ups.

## Layout / Routing Notes

- Route USB D+/D− as a short matched differential pair, avoid long stubs, and keep any ESD/protection parts close to the USB connector.
- Keep CAN termination jumper-selectable and normally open by default.
- Keep domain labels (`GND_CA`, `GND_CB`, `GNDI`, `GNDE`) visible in the schematic and layout so harness/debug wiring does not accidentally short isolated/reference domains.

## Thermal Considerations

### MOSFET Stage
At 200A spike through main MOSFETs with Rdson = 1 mΩ (paralleled):
- P = I² × R = 200² × 0.001 = 40W (transient, < 2 s)

At 100A continuous with Rdson = 1 mΩ:
- P = I² × R = 100² × 0.001 = 10W (continuous)

Adequate copper area and/or heatsinking is required for the MOSFET stage.

### Fuse
The AMXL-250 ceramic fuse handles its own thermal management. Mounting on screw terminals provides thermal mass and heat dissipation through the PCB copper.

### Buck Converter
At 1A output, 5V, from 75.6V input — even at 85% efficiency the dissipation is modest:
- P_in = 5.0 / 0.85 = 5.88W
- P_loss = 5.88 − 5.0 = 0.88W

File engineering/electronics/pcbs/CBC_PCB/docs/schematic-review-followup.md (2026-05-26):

# CBC_PCB — Schematic Review Follow-up

This page tracks the accepted follow-up items from the CBC schematic review pass.

## Documentation approach

Keep design intent in three project-local places:

1. `README.md` — stable board overview, sheet interface summary, high-level architecture.
2. `docs/connector-pinout.md` — connector and harness-facing behavior, including wiring/domain notes.
3. `docs/power-architecture.md` — power tree, protection, fusing, redundancy, and routing-critical power notes.

Short-lived implementation reminders from schematic review are tracked below until they are either implemented in KiCad or promoted into the stable docs.

## Review follow-up table

| Review item | Decision / action |
|---|---|
| 4 — Main current hardware protection | Main fuse is mounted on J4/J5 using the bolt-in AMT0650009DB0000G fuse terminal arrangement. Documented as the primary high-current short-circuit protection. |
| 5 — Kill/off fail-safe documentation | Document the hardware kill behavior, latch behavior, external `12V_TRIGGER_SIG`, and expected recovery/re-arm sequence in the power architecture docs. |
| 6 — `12V_ISOLATED` short protection | Add another `0154005.DR` fuse to the isolated 12V output path before the AT13 connector / harness output. |
| 7 — ESP GPIO latched enable safety | `ESP_ENABLE_SIGNAL` already has a 10k pulldown (`R16`). Keep this documented as the default-off state for the latch input. |
| 8 — USB back-powering `+5V` | Accepted as low risk because USB mostly powers ESP32/debug logic. No schematic change required. |
| 9 — ESP32 `GPIO0` pull-up | Add/document an external pull-up option on `GPIO0` so the ESP32 boot strap is deterministic even with USB-UART/autoprogramming circuitry attached. |
| 10 — MCP2515 `CS#1` / `CS#2` pull-ups | Add pull-ups to keep both MCP2515 chip-select lines inactive during ESP32 reset/boot. |
| 11 — MCP2515 `INT#1` / `INT#2` pull-ups | Document that the MCP2515 interrupt outputs are used with ESP32 pull-ups unless the schematic later adds external pull-ups. Confirm MCP2515 output mode during firmware bring-up. |
| 12 — USB layout | Routing task: route USB D+/D− as a short matched differential pair, avoid stubs, and keep ESD/protection close to connector if added. |
| 13 — J2 ground-domain mixing | Intentional. Document harness wiring so installers understand which ground/domain each pin belongs to. |
| 14 — CAN isolated-side reference strategy | Battery CAN exposes only `CANH_BAT`/`CANL_BAT`; `GND_CA` is not normally carried to the battery. Drone CAN `GND_CB` may be carried to CMAIN_PCB and tied with the other CBC `GND_CB` references there. |
| 15 — CAN termination | Termination is jumper-selectable and normally deactivated by default. |
| 16 — J2 / AT13 footprint pin numbering | Still requires manual review against connector datasheet and harness pinout before manufacturing release. |
| 17 — Connector docs | Connector and harness notes updated in `connector-pinout.md`. |
| 18 — Sheet interfaces | Added a top-level sheet interface table to `README.md`. |
| 19 — `DATA1` / `DATA2` naming | Renamed to `TEMP1_DQ` / `TEMP2_DQ`. |
| 20 — Label direction cleanup | Cleaned global label directions for SPI, MCP2515 interrupt/chip-select, CAN bus, and 1-Wire temperature nets. |
| 21 — Custom power symbols | Keep current custom/renamed power symbols for now. |
| 22 — PWR_FLAG / power pin modeling | ERC/power modeling reviewed after changes. Keep PWR_FLAGs only where they represent an intentional supply source/modeling boundary. |
| 23 — DS18B20 warning | Footprint/filter warning is intentionally excluded from checks. |

## Notes for next schematic/layout pass

- Add `0154005.DR` fuse on the isolated 12V output.
- Add pull-ups on `CS#1` and `CS#2`.
- Decide whether `GPIO0` gets a fitted pull-up or a DNI pull-up option.
- Keep CAN termination jumper-selectable and default-open.
- Add USB routing constraints to the PCB layout checklist.

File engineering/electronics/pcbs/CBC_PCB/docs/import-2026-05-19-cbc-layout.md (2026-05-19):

# CBC_PCB KiCad layout import — 2026-05-19

Imported from Julius's `18SBC_PCB_19052026` package.

## Integration notes

- Renamed the KiCad root project files from `18SBC_PCB` to `CBC_PCB` to match the repository folder/project naming.
- Placed the KiCad source under `engineering/electronics/pcbs/CBC_PCB/kicad/`.
- Consolidated schematic symbols into `kicad/libs/CBC_PCB.kicad_sym` and rewrote non-power `lib_id` references to the `CBC_PCB` project library.
- Consolidated available discrete/custom footprint files into `kicad/libs/CBC_PCB.pretty/`.
- Moved included STEP/model assets under `kicad/libs/3dmodels/` and updated board model paths accordingly.
- Copied `CBC_PCB.step` and `fabrication-toolkit-options.json` to `manufacturing/`.

## Caveat

The zip did not include an `EasyEDA_Lib.elibz` source library even though the original project tables referenced it. The imported schematic sheets and board retain embedded EasyEDA symbol/footprint definitions, and the consolidated `CBC_PCB.kicad_sym` contains the embedded schematic symbols. If we want a fully reusable EasyEDA-derived footprint library later, export those footprints explicitly from KiCad/EasyEDA and add them to `CBC_PCB.pretty`.

## Import validation

Ran with KiCad CLI 10.0.1 after integration:

- `kicad-cli sch export netlist kicad/CBC_PCB.kicad_sch -o /tmp/cbc.net` succeeded.
- `kicad-cli pcb export step kicad/CBC_PCB.kicad_pcb -o /tmp/cbc_import.step` succeeded and produced a 57 MB STEP export.
- `kicad-cli sch erc` currently reports 1491 violations on the initial design, mostly dangling wires/labels.
- `kicad-cli pcb drc` currently reports 256 DRC violations and 115 unconnected items.
- The source package references `EASYEDA_MODELS/C1206_L3.2-W1.6-H1.3.step`, but that model file was not present in the zip; KiCad can still export STEP, with warnings for the affected C1206 capacitors.

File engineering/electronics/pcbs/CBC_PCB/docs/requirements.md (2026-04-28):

# CBC_PCB — Requirements

## 1. Scope

The Caribou Battery Connector PCB (CBC) is a per-arm board in the Project Caribou hexacopter. It interfaces one 18S Tattu 4.0 smart battery with one Hobbywing XRotor X15 propulsion unit. Six identical CBC boards are used in total — one per motor arm.

## 2. Electrical Requirements

### 2.1 Power Path

| Requirement | Value | Rationale |
|---|---|---|
| Input Voltage Range | 54.0–75.6V (18S Li-Ion, 3.0–4.2V/cell) | Tattu 4.0 18S battery operating range |
| Continuous Current | ≥ 100A | Covers hover (~45A) and moderate climb (~100A) |
| Spike Current | ≥ 200A for ≥ 2 seconds | Full-throttle burst, e.g. emergency climb-out |
| Short-Circuit Protection | Fuse ≥ 200A, ≤ 300A | Must not nuisance-blow at 200A spike; must clear faults |
| Precharge | Soft-start inrush limiting | Protect ESC input capacitors from inrush damage |
| Kill Switch | Hardware-level, MCU-independent | Safety requirement — must disable power even if MCU is unresponsive |

### 2.2 Voltage Regulation

| Output | Voltage | Current | Isolation | Domain | Purpose |
|---|---|---|---|---|---|
| Internal 5V | 5.0V ± 5% | ≥ 1A | Non-isolated | GNDI | Onboard logic supply |
| Internal 3.3V | 3.3V ± 3% | ≥ 500 mA | Non-isolated (LDO from 5V) | GNDI | ESP32, MCP2515, CAN transceivers |
| External 12V | 12.0V ± 5% | ≥ 10A | Galvanically isolated | GNDE | Aircraft avionics via CMAIN_PCB |

### 2.3 Communication

| Interface | Protocol | Purpose |
|---|---|---|
| CAN 1 | Battery-proprietary (Tattu smart battery protocol) | Read battery state, SoC, cell voltages, temperature |
| CAN 2 | DroneCAN (UAVCAN v0) | Report battery status to ArduPilot via CMAIN_PCB |
| WiFi | 802.11 b/g/n (2.4 GHz) | Wireless diagnostics, configuration, firmware update |
| BLE | BLE 5.0 | Low-power wireless diagnostics |

### 2.4 Sensing

| Measurement | Method | Purpose |
|---|---|---|
| Board Temperature | 1-Wire (DS18B20) or NTC via ADC | Thermal monitoring of power path |
| HV Bus Voltage | Resistive divider → ADC | Voltage monitoring, under/over-voltage protection |

## 3. Mechanical Requirements

| Requirement | Value |
|---|---|
| Board Shape | Rectangular |
| Mounting | TBD |
| Battery Connector Orientation | Right-angle DIP (vertical mate with battery) |
| Signal Connector Orientation | Right-angle flange mount |
| Environmental | Outdoor operation, vibration environment (near motor arm) |

## 4. Connector Requirements

| Connector | Part Number | Function |
|---|---|---|
| Battery Interface | Prolanv EN60A | Mates with Tattu 4.0 (ACES 59604-0169D-003) |
| Propulsion Output | 2× Amphenol AMT0650009DB0000G | High-current screw terminals for motor cables |
| Fuse Mount | 2× Amphenol AMT0650009DB0000G | Bolt-in mount for Eaton AMXL-250 |
| Signal / Drone Interface | Amphenol AT13-12PB-BM03 | 12-pos harness to CMAIN_PCB |

## 5. Firmware Requirements

| Requirement | Details |
|---|---|
| CAN Protocol Bridge | Translate Tattu battery protocol (CAN 1) → DroneCAN battery status messages (CAN 2) |
| CAN Library | `libcanard` (lightweight UAVCAN v0 implementation) |
| Power Sequencing | Manage precharge → enable → run state machine |
| Kill Switch Response | Immediate power cutoff on hardware kill input, independent of firmware state |
| OTA Updates | Firmware update via WiFi (ESP32-C3 OTA capability) |
| Diagnostics | Expose battery state, temperatures, voltages via WiFi/BLE for ground testing |

## 6. Safety Requirements

| Requirement | Rationale |
|---|---|
| Kill switch must be hardware-level | Ensures power cutoff even if MCU hangs or firmware crashes |
| Fuse must be field-replaceable | Blown fuse = swap and fly, no soldering required |
| Isolation between GNDI and GNDE | Fault on aircraft bus must not affect battery management logic |
| No single-point power failure propagation | One CBC failure must not cascade to other motor arms |

## 7. Design Constraints

- EDA tool: **KiCad 10**
- All custom symbols, footprints, and 3D models must be stored in `kicad/libs/` (no reliance on contributor-specific global libraries)
- PCB naming convention follows Caribou project standards
- Firmware in `firmware/` directory, buildable with ESP-IDF or Arduino framework

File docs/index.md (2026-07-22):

---
title: Intro
sidebar_label: Intro
sidebar_position: 1
description: Introduction to Project Caribou
---

# Project Caribou

Project Caribou

Project Caribou is an open-source heavy-lift hexacopter for cargo logistics and precision agriculture, developed by [Arrow](https://arrowair.com). With a target maximum takeoff weight of ~200 kg and ~100 kg of payload capacity, Caribou is designed to take on work currently flown by helicopters and light aircraft — large-area spraying, spreading, and heavy cargo delivery — at a fraction of the operating cost.

Caribou builds directly on lessons from Project Feather and Project Quiver: distributed custom PCBs, CAN-based smart battery telemetry, and a design philosophy centered on ruggedness, field repairability, and cost-effective manufacturing.

All design files and documentation are released under the [CERN Open Hardware Licence v2 — Strongly Reciprocal](https://ohwr.org/cern_ohl_s_v2.txt).

## Key Capabilities

- **Heavy lift** — ~100 kg payload capacity for cargo delivery or ~80 L liquid spraying missions
- **Powerful off-the-shelf propulsion** — 6× Hobbywing XRotor X15 propulsion units with 63" (1600 mm) propellers, rated at up to 72 kg maximum thrust per rotor
- **High-voltage architecture** — 18S (~75 V) power system for PT1 with Tattu smart batteries, external HV kill switch, pre-charge circuitry, and redundant power supply
- **Custom electronics** — purpose-built battery connector PCB (CBC) and main PCB (CMAIN) handling power distribution, battery telemetry, and safety switching
- **Redundant avionics** — triple-redundant IMU, GPS, and compass running ArduPilot, compatible with QGroundControl and Mission Planner
- **Hybrid airframe** — welded steel/aluminum core structure with detachable motor arms for transport and field service

## Why Caribou

Agricultural spraying and spreading jobs at this scale are flown today with helicopters and fixed-wing aircraft. A heavy-lift multirotor that can be trucked to a field, assembled by a small crew, and operated at far lower cost per flight hour opens that work to many more operators.

For Arrow, Caribou is also a milestone: it is the largest aircraft the DAO has built, and a deliberate step on the roadmap from small drones toward larger — and eventually manned — aircraft.

## Development Status

Caribou is in the **PT1 (proof of concept)** phase. The PT1 goal is to validate the structural design and high-voltage power architecture, with a stable tethered hover as the milestone.

As of mid-2026:

- The PT1 frame structure is built
- CMAIN and CBC PCBs are manufactured, with 3D-printed enclosures complete
- First motor tests are the next step, leading toward hover testing
- A second build is planned in Texas to validate reproducibility
- PT2 concept brainstorming is underway on the [DAO forum](https://dao.arrowair.com)

Progress is discussed in weekly Caribou calls; notes are posted in the repository and on Discord.

## Repository Structure

```
project-caribou/
├── engineering/            # Active design work
│   ├── cad/                # CAD sources, reference geometry, exports
│   └── electronics/        # Self-contained KiCad PCB projects
│       └── pcbs/
│           ├── CBC_PCB/    # Battery connector PCB (+ firmware)
│           └── CMAIN_PCB/  # Main PCB
├── docs/                   # This documentation site
│   └── pt1/                # PT1 engineering report, manufacturing & user guides
└── src/                    # General source area
```

## Get Involved

- **Discord** — [discord.gg/arrow](https://discord.gg/arrow), `#project-caribou-general`
- **DAO Forum** — [dao.arrowair.com](https://dao.arrowair.com)
- **GitHub** — [Arrow-air/project-caribou](https://github.com/Arrow-air/project-caribou)

Caribou is developed in the open. Design discussions, test results, and decisions happen in public — contributions, questions, and reviews are welcome.

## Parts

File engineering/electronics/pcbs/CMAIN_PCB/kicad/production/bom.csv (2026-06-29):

Designator | Footprint | Quantity | Value | LCSC Part #
C1, C27, C28, C3, C31, C4, C5 | 0805 | 7 | 100nF 50V | CC0805KRX7R9BB104
C10, C11, C12, C15, C16, C9 | C1206 | 6 | 10uF 50V | GCM31CC71E106KA03L
C13, C14, C17, C18, C20, C21 | CAP-TH_BD10.0-P5.00-D0.6-FD_2 | 6 | 100uF 100V | EEU-FC1E101S
C2, C26, C33, C35, C36, C40, C42, C43, C8 | 0805 | 9 | 0.1uF 50V
C22, C38, C45 | 0603 | 3 | 22pF 50V
C23, C24, C34, C39, C41, C46 | C1206 | 6 | 22uF 25V
C25, C37, C44 | 0805 | 3 | 1uF 50V
C29, C30, C32 | 0805 | 3 | 0.47uF 50V | CC0805KKX7R9BB474
C6, C7 | 0603 | 2 | 8pF 50V | CC0603JRNPO9BN8R0
CN13, CN14, CN15, CN16 | SCREW-SMD_TH162050CTJ | 4 | ~
D1, D2 | DIONC1608X55N | 2 | PESD0603-240 | PESD0603-240
D10, D11, D18, D19, D20, D21, D22, D23, D24, D25, D26, D9 | LED_APT2012SURCK | 12 | APT2012SURCK
D12, D13, D14, D15, D16, D17 | D_SMB | 6 | SMBJ20A | C19077568
D3, D4 | D_SMB | 2 | SMBJ13CA | C19077568
D5 | SOT-23-6_L2.9-W1.6-P0.95-LS2.8-BL | 1 | USBLC6-2SC6
D6, D7 | SMB_L4.6-W3.6-LS5.3-RD | 2 | SS34
D8 | SMA_L4.3-W2.6-LS5.0-FD | 1 | SS14
F1, F7 | 0154002DR | 2 | 0154002.DR
F2, F3, F4 | 0154005DR | 3 | 0154005.DR
F8 | 1812L010DR | 1 | 1812L110_24DR
IC1 | QFN65P400X400X90-17N | 1 | TSYS01
J1 | SSM-120-XXX-DV | 1 | RPI_5_WITH_SSQ-120-01-F-D
J10, J16, J19, J2, J21, J24, J50, J6 | 1778719 | 8 | 1778719
J12, J13, J23, J27, J32, J37, J38, J39, J40, J43, J45, J46, J48, J49, J52, J53, J55, J56, J57, J8 | B04B-JWPF-SK-R | 20 | B04B-JWPF-SK-R
J14 | XT30PW-F_AMASS_XT30PW-F | 1 | XT30PW-F
J15, J35, J5, J7 | SM04B-GHS-TB | 4 | SM04B-GHS-TB_LF__SN_
J17 | CONN-TH_SM03B-GHS-TB-LF-SN | 1 | SM03B-GHS-TB(LF)(SN)
J25, J26, J28, J34, J42, J44 | B08B-JWPF-SK-R | 6 | B08B-JWPF-SK-R
J29, J30, J31 | B06B-JWPF-SK-R | 3 | B06B-JWPF-SK-R
J3, J4 | AXK6S00547YG | 2 | AXK6S00547YG
J36 | SM05B-GHS-TB | 1 | SM05B-GHS-TB_LF__SN_
J41 | SM06B-GHS-TB | 1 | SM06B-GHS-TB_LF__SN_
J47, J51 | fp_072ec239da | 2 | GIGABLOX_NANO_SWITCH_REVA_MODULE
J9 | SM04B-GHS-TB_J9 | 1 | SM04B-GHS-TB_LF__SN_
K1, K10, K2, K4, K5, K6, K7, K8, K9 | SOP254P610X218-4N | 9 | CPC1019N
L1, L2, L3 | IND-SMD_CYA0650-3.3UH | 3 | 3.3uH
LED4, LED5 | LEDC2012X85N | 2 | APT2012LVBC_D
LS1 | CMT8530SSMTTR | 1 | CMT-8530S-SMT-TR
Q1, Q2 | fp_a2a0cc2e74 | 2 | SIRA99DP-T1-GE3
Q4, Q5, Q6, Q7, Q8, Q9 | POWERPAK-SO-8_L5.9-W4.9 | 6 | PSMN4R3-30BL,118 | PSMN4R3-30BL,118
R1, R22, R26, R27, R42, R43, R44, R45, R46 | 0805 | 9 | 1K5 150V
R10, R11, R17, R19, R20, R21 | 0805 | 6 | 10k 150V | RC0805FR-0710KL
R12, R13 | 0805 | 2 | 5K1 150V
R14, R18 | 0805 | 2 | 120R 150V | RC0805FR-07120RL
R16 | 0805 | 1 | 0R 150V | RC0805FR-070RL
R2, R23, R33, R36, R4, R5 | 0805 | 6 | 100k 150V
R24, R34, R37 | 0805 | 3 | 75K 150V
R25, R35, R38, R7, R9 | 0805 | 5 | 10K 150V
R28, R31, R32, R39, R40, R41 | 0805 | 6 | 1R 150V
R29, R30 | 0805 | 2 | 4K7 150V
R3, R6 | 0805 | 2 | 100R 150V
R47 | 0805 | 1 | 47K 150V
R50, R51, R52, R53, R54, R55, R74, R75, R76 | 0805 | 9 | 2K 150V | RC0805FR-072KL
R67, R68, R69, R70, R71, R72 | 2512 | 6 | 2mR | PA2512FKE070R002E
R77, R78, R79 | 0805 | 3 | 560R 150V
R8 | 0805 | 1 | 100k 150V | RC0805FR-0710KL
S1, S2 | SLW9135352ASMT | 2 | SLW-913535-2A-SMT | SLW-913535-2A-SMT
U1 | SOIC127P600X175-8N | 1 | TJA1049T/3J | TJA1049T/3J
U13, U14, U15, U16 | WAFER-GH1.25-4PLB | 4 | ~
U17, U18, U4 | VREG_SY8205FCC | 3 | SY8205FCC
U19, U20, U21, U5 | SMD_SMTSO3060CTJ | 4 | SMTSO3050CTJ
U2 | SOIC127P1030X265-18N | 1 | MCP2515-I/SO | MCP2515-I/SO
U29, U30, U31 | MSOP-16_3x4.039mm_P0.5mm | 3 | LTC4370IMS#PBF | LTC4370IMS#PBF
U3, U6, U7, U8 | SMD_BD6.0-D4.2 | 4 | SMTSOM380BTR
USB33 | USB-C-SMD_TYPEC-303-ACP16 | 1 | TYPEC-303-ACP16
X1 | NX3225GB-16M-STD-CRA-2 | 1 | 16MHz | NX3225GB-16M-STD-CRA-2

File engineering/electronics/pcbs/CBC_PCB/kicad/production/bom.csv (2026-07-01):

Designator | Footprint | Quantity | Value | LCSC Part #
C201 | EasyEDA_Lib_2:CAP-SMD_BD6.3-L6.6-W6.6-LS7.4-FD | 1 | 100uF | C1517616
C202,C632 | EasyEDA_Lib:C0805 | 2 | 1uF | C5370002
C203,C204,C302,C305,C307,C407,C408,C414,C416,C420 | EasyEDA_Lib:C0805 | 10 | 10uF | C440198
C205,C206,C207,C208,C601,C602,C603,C604,C644,C646 | EasyEDA_Lib_2:C2220 | 10 | 2.2uF | C153032
C209,C210,C211,C212,C213,C214,C215,C216,C223,C224,C227,C605,C606,C607,C608,C616,C617,C626,C627,C634,C635,C639,C640 | EasyEDA_Lib:C0603 | 23 | 100nF | C15725
C217,C218,C219,C220,C221,C222,C225,C226,C301,C405,C406,C412,C413,C618,C619,C620,C621,C622,C623 | EasyEDA_Lib:C0805 | 19 | 4.7uF | C98192
C303 | EasyEDA_Lib:C0402 | 1 | 1uF | C7472946
C304,C306,C409,C410,C421,C501,C502 | EasyEDA_Lib:C0402 | 7 | 100nF | C60474
C401,C402,C403,C404 | EasyEDA_Lib:C0402 | 4 | 22pF | C106203
C411,C415 | Capacitor_SMD:C_0805_2012Metric_Pad1.18x1.45mm_HandSolder | 2 | 100nF
C417 | EasyEDA_Lib_2:C0805 | 1 | 100pF | C599828
C418,C419,C422,C423 | EasyEDA_Lib:C0402 | 4 | 220pF | C71693
C609 | EasyEDA_Lib_2:CAP-SMD_BD10.0-L10.3-W10.3-FD-LS11.0 | 1 | 47uF | C49424130
C610 | EasyEDA_Lib:C0805 | 1 | 470pF | C107138
C611,C612,C614,C624,C645 | EasyEDA_Lib:C1206 | 5 | 4.7uF | C237304
C613 | EasyEDA_Lib_2:C0805 | 1 | 33nF | C327114
C615 | EasyEDA_Lib:C0603 | 1 | 220nF | C64705
C625 | EasyEDA_Lib:C0603 | 1 | 47pF | C1671
C628 | EasyEDA_Lib:C0603 | 1 | 4.7nF | C327158
C629,C630,C631,C633,C638,C641 | EasyEDA_Lib:C1206 | 6 | 47uF | C403725
C636,C637,C642,C643 | EasyEDA_Lib:CAP-SMD_L3.5-W2.8-R-RD | 4 | 10uF | C7194
CN201 | EasyEDA_Lib:CONN-SMD_A1257WV-S-2P | 1 |  | C225118
D201,D202 | EasyEDA_Lib_2:SOD-323_L1.8-W1.3-LS2.5-RD | 2 |  | C2128
D203,D217 | EasyEDA_Lib:SMB_L4.3-W3.6-LS5.4-BI | 2 | SMBJ78CA | C2903953
D204,D205,D208,D209,D210,D211,D214,D219 | EasyEDA_Lib:SMB_L4.6-W3.6-LS5.4-BI | 8 |  | C19077568
D206,D207 | EasyEDA_Lib_2:SMA_L4.3-W2.6-LS5.2-RD | 2 |  | C47779
D212,D213,D606,D607 | EasyEDA_Lib:SMB_L4.6-W3.6-LS5.3-BI | 4 |  | C83323
D215,D218 | Diode_SMD:D_SMA | 2 | SS34
D216 | lcsc_footprints:C719814_TO-277A_L5_9-W4_4-LS6_5-TR | 1 | FSV10150V | C719814
D301 | EasyEDA_Lib:SMA_L4.3-W2.6-LS5.0-FD | 1 |  | C7420316
D302 | EasyEDA_Lib:SOT-23-6_L2.9-W1.6-P0.95-LS2.8-BL | 1 |  | C7519
D401,D403 | Samacsys:DIONC1608X55N | 2 | PESD0603-240
D402 | EasyEDA_Lib_2:SOT-323-3_L2.0-W1.3-P1.30-LS2.1-BR | 1 |  | C152727
D404 | EasyEDA_Lib:SOT-23-3_L2.9-W1.3-P1.90-LS2.4-BL-2 | 1 |  | C14486
D601,D602 | EasyEDA_Lib_2:SMB_L4.6-W3.6-LS5.3-RD | 2 |  | C47124
D603 | EasyEDA_Lib:SMB_L4.6-W3.6-LS5.3-RD | 1 |  | C135108
D604 | EasyEDA_Lib:SOD-123FL_L2.8-W1.8-LS3.8-RD | 1 |  | C5354735
D605,D608 | EasyEDA_Lib:SOD-123_L2.7-W1.6-LS3.7-RD-1 | 2 |  | C260853
D609 | EasyEDA_Lib:SMB_L4.6-W3.6-LS5.3-RD | 1 |  | C151789
D610 | EasyEDA_Lib:SMB_L4.6-W3.6-LS5.3-RD | 1 |  | C284082
F201,F603 | EasyEDA_Lib:FUSE-SMD_L9.8-W5.1 | 2 | 0154005.DR | C206916
F202,F203,F601,F602 | EasyEDA_Lib:FUSE-SMD_L9.8-W5.1 | 4 |  | C206908
H401,H402 | EasyEDA_Lib:HDR-TH_2P-P2.54-V-M | 2 |  | C492401
HC201,HC202 | CBC_PCB:C90D_PAD | 2 | C90D_PAD
J201,J202,J203,J204 | CBC_PCB:AMT0650009DB0000G | 4 | AMT0650009DB0000G
J501 | CBC_PCB:B08B-JWPF-SK-R | 1 | B08B-JWPF-SK-R
L201,L202 | EasyEDA_Lib_2:IND-SMD_L5.0-W5.0-P3.60_SMNR5040 | 2 | 33uH | C9390
L401 | EasyEDA_Lib:FILTER-SMD_4P-L4.5-W3.2_ACT45B-510-2P | 1 |  | C48928226
L601 | EasyEDA_Lib_2:IND-SMD_L6.6-W6.4 | 1 | 22uH | C5366013
L602,L603 | EasyEDA_Lib_2:IND-SMD_L6.0-W6.0_SMNR6045 | 2 | 33uH | C135306
L604 | EasyEDA_Lib:XFMR-SMD_12P-L22.1-W21.8-P3.00-LS29.2-BL | 1 | 20.5uH | C5723154
LED201,LED202,LED203,LED301,LED601,LED602,LED603 | EasyEDA_Lib:LED0603-RD | 7 |  | C12624
Q201,Q205,Q206,Q207,Q208,Q209,Q210 | EasyEDA_Lib:TOLL-8_L10.4-W9.9-P1.20-LS11.7-BL | 7 |  | C22385354
Q202,Q203 | lcsc_footprints:C2846922_SOT-323-3_L2_0-W1_3-P1_30-LS2_1-BR | 2 | LMUN5235T1G | C2846922
Q204 | EasyEDA_Lib:TOLL-8_L10.4-W9.9-P1.20-LS11.7-BL | 1 | SP015N03BGHTO | C22385354
Q301 | EasyEDA_Lib:SC-70-6_L2.2-W1.3-P0.65-LS2.1-BR | 1 |  | C62892
Q601 | CBC_PCB:DFN-8_L5.9-W5.2-P1.27-LS6.2-BL | 1 |  | C501501
Q602 | CBC_PCB:DFN-8_L5.9-W5.2-P1.27-LS6.2-BL | 1 |  | C501500
R201,R207,R212,R217,R223,R226,R227,R235,R237,R242,R301,R401,R402 | EasyEDA_Lib:R0402 | 13 | 10kΩ | C190095
R202 | EasyEDA_Lib_2:R0805 | 1 | 15kΩ | C114559
R203 | EasyEDA_Lib_2:R0805 | 1 | 120kΩ | C114524
R204 | EasyEDA_Lib_2:R0805 | 1 | 36kΩ | C114527
R205 | EasyEDA_Lib_2:R0805 | 1 | 10kΩ | C84376
R206 | EasyEDA_Lib:R0402 | 1 | 330Ω | C105875
R208,R209 | EasyEDA_Lib:R2512 | 2 | 10Ω | C47019
R210,R214,R218,R225,R228,R236,R240 | lcsc_footprints:C25076_R0402 | 7 | 100Ω | C25076
R211,R213 | lcsc_footprints:C106231_R0402 | 2 | 0 | C106231
R215,R216 | lcsc_footprints:C114617_R0603 | 2 | 300 | C114617
R219,R221 | EasyEDA_Lib:R0603 | 2 | 590K, 0603
R220,R222,R232,R234,R605,R607,R614,R616 | EasyEDA_Lib:R0603 | 8 | 10kΩ | C95204
R224 | lcsc_footprints:C125758_R0603 | 1 | 20 | C125758
R229,R230 | EasyEDA_Lib:RES-TH_BD7.5-L20.0-P24.00-D1.0 | 2 | 33Ω | C511506
R231,R233,R613,R615 | EasyEDA_Lib:R0603 | 4 | 140kΩ | C47115952
R238,R239,R241,R625 | EasyEDA_Lib:R0603 | 4 | 1.8kΩ | C4177
R302 | EasyEDA_Lib:R0603 | 1 | 39Ω | C23154
R303,R304 | EasyEDA_Lib:R0402 | 2 | 5.1kΩ | C25905
R403 | Resistor_SMD:R_0805_2012Metric_Pad1.20x1.40mm_HandSolder | 1 | 0R
R404 | Resistor_SMD:R_0805_2012Metric_Pad1.20x1.40mm_HandSolder | 1 | 10K
R405,R408 | EasyEDA_Lib:R0603 | 2 | 120Ω | C22787
R406 | EasyEDA_Lib_2:R0805 | 1 | 1MΩ | C107700
R407,R611 | EasyEDA_Lib:R0402 | 2 | 0Ω | C106231
R501,R502 | EasyEDA_Lib:R0402 | 2 | 4.7kΩ | C105871
R601 | EasyEDA_Lib:R0603 | 1 | 6.04kΩ | C25977
R602 | EasyEDA_Lib:R0603 | 1 | 60.4kΩ | C23089
R603 | EasyEDA_Lib:R0603 | 1 | 7.5kΩ | C2930127
R604,R606 | EasyEDA_Lib:R0603 | 2 | 240kΩ | C705831
R608 | EasyEDA_Lib:R0805 | 1 | 1.2MΩ | C2933294
R609 | EasyEDA_Lib:R0603 | 1 | 51kΩ | C351642
R610 | EasyEDA_Lib:R0805 | 1 | 160kΩ | C17485
R612 | EasyEDA_Lib:R0805 | 1 | 68Ω | C445645
R617,R623 | EasyEDA_Lib:R0805 | 2 | 3Ω | C17660
R618,R619,R621,R626,R627 | EasyEDA_Lib:R0603 | 5 | 100Ω | C394538
R620,R622 | EasyEDA_Lib:R0603 | 2 | 390Ω | C23151
R624 | EasyEDA_Lib:R0603 | 1 | 2.37kΩ | C2933174
SW301 | EasyEDA_Lib:SW-SMD_L3.9-W3.0-P4.45 | 1 |  | C720477
U201 | EasyEDA_Lib:UDFN-8_L1.5-W1.0-P0.35-BL | 1 | 74LVC2G02HK3-7 | C842632
U202 | EasyEDA_Lib:SOT-25-5_L3.0-W1.8-P0.95-LS3.0-BL | 1 | 74LVC1G17W5-7 | C151394
U203 | EasyEDA_Lib:SOP-4_L4.1-W3.8-P2.54-LS6.1-BL | 1 | CPC1106NTR | C5341660
U204,U205,U601,U602 | CBC_PCB:SOIC-8EP_MP9486_MNP | 4 | MP9486GN-Z
U206,U207 | lcsc_footprints:C42432174_SOP-6_L6_8-W4_6-P1_27-LS11_7-BL | 2 | ICPL-314P-500EAXW | C42432174
U208,U209 | CBC_PCB:SMD_BD6.0-D4.2 | 2 | BSMTSOM330BTR | C20617225
U301 | EasyEDA_Lib:WIRELM-SMD_ESP32-S3-WROOM-1 | 1 | 2.4GHz | C2913202
U302 | EasyEDA_Lib:QFN-24_L4.0-W4.0-P0.50-BL-EP2.7 | 1 |  | C47742
U401,U402 | EasyEDA_Lib:TSSOP-20_L6.5-W4.4-P0.65-LS6.4-BL | 2 |  | C185941
U403 | Samacsys:SOIC127P600X175-8N | 1 | TJA1049T/3J
U404 | EasyEDA_Lib:SOIC-20_L13.0-W7.6-P1.27-LS10.3-BL | 1 | ADM3053BRWZ-REEL7 | C117821
U501,U502 | EasyEDA_Lib:SOIC-8_L4.9-W3.9-P1.27-LS6.0-BL | 2 |  | C97190
U603 | EasyEDA_Lib_2:C0805 | 1 | 1uF | C5370002
U604 | EasyEDA_Lib:MSOP-16_12P-L4.0-W3.0-P0.50-LS4.9-BL | 1 |  | C117158
U605 | EasyEDA_Lib:C0603 | 1 | 120pF | C1864338
U606 | EasyEDA_Lib:R1206 | 1 | 10mΩ | C20608707
U607,U608,U613,U614 | EasyEDA_Lib:MAX40203AUK_T_SOT-23-5 | 4 | MAX40203AUK+T | C2653639
U609 | EasyEDA_Lib:IND-SMD_L6.6-W6.4_XAL6060-103ME | 1 | 1uH | C2938919
U610 | EasyEDA_Lib:TSOT-23-5_L2.9-W1.6-P0.95-LS2.8-BR | 1 |  | C580284
U611,U612 | EasyEDA_Lib:SOT-223-3_L6.5-W3.4-P2.30-LS7.0-BR | 2 |  | C6186
USB301 | EasyEDA_Lib_2:USB-C-SMD_TYPEC-303-ACP16 | 1 |  | C720628
X401,X402 | EasyEDA_Lib:CRYSTAL-SMD_L3.2-W2.5_3225-8MHZ | 2 | 16MHz | C481399

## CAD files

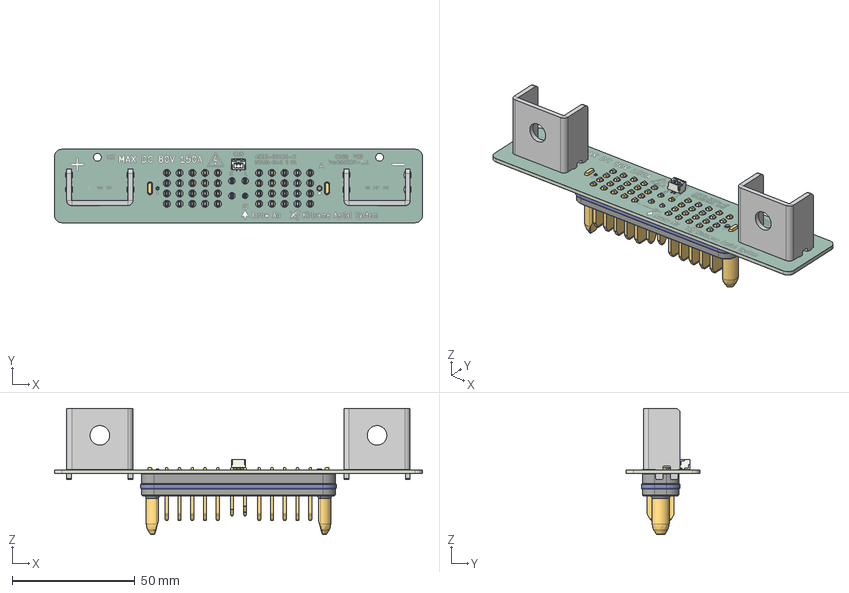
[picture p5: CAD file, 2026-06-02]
engineering/electronics/pcbs/C90D_PCB/manufacturing/C90D_PCB.step
150.0 x 30.0 x 51.5 mm
JST_GH_BM02B-GHS-TBT_1x02-1MP_P1.25mm_Vertical
EL-Connect-003-OT-201-M8 x 2
EL-Connect-ACE-59626-XXXXX-XXX
C90D_PCB_copper
C90D_PCB_silkscreen x 2
C90D_PCB_soldermask x 2
C90D_PCB_PCB

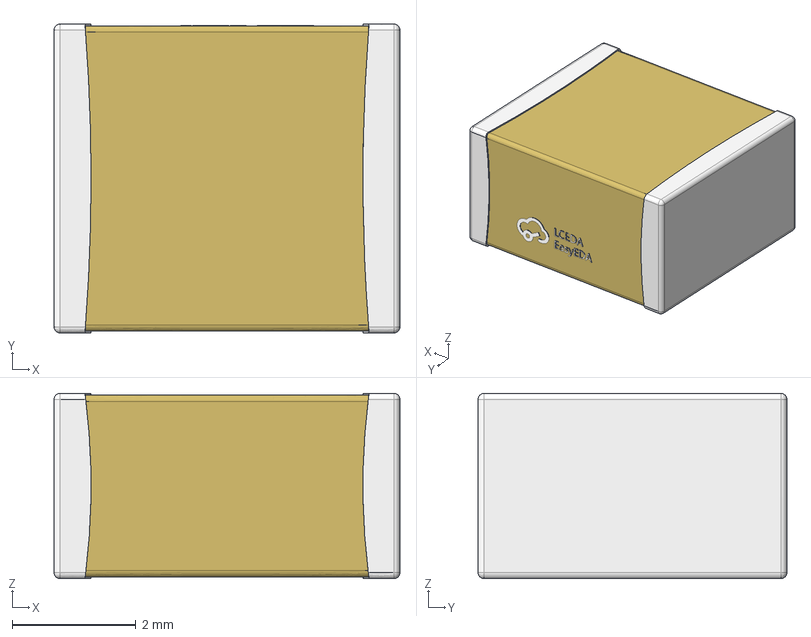
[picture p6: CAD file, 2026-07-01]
engineering/electronics/pcbs/CBC_PCB/kicad/EASYEDA_MODELS/C2220_L5.6-W5.0-H3.0.step
5.60 x 5.00 x 3.00 mm

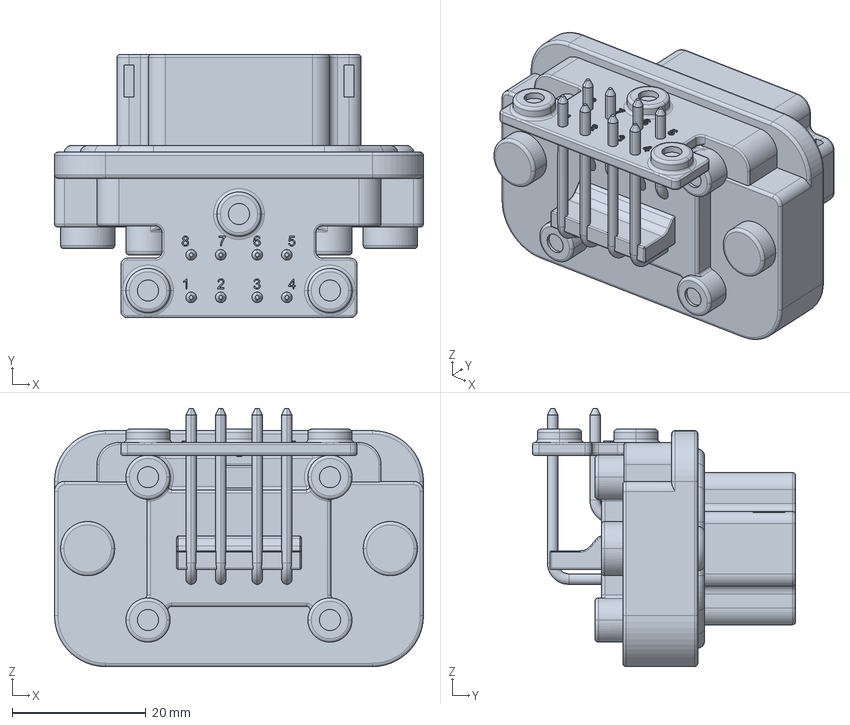
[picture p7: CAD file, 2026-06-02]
engineering/electronics/pcbs/CMAIN_PCB/kicad/ALTIUM_EMBEDDED_MODELS/AT13-08PA-BM01.stp
55.1 x 39.4 x 38.6 mm

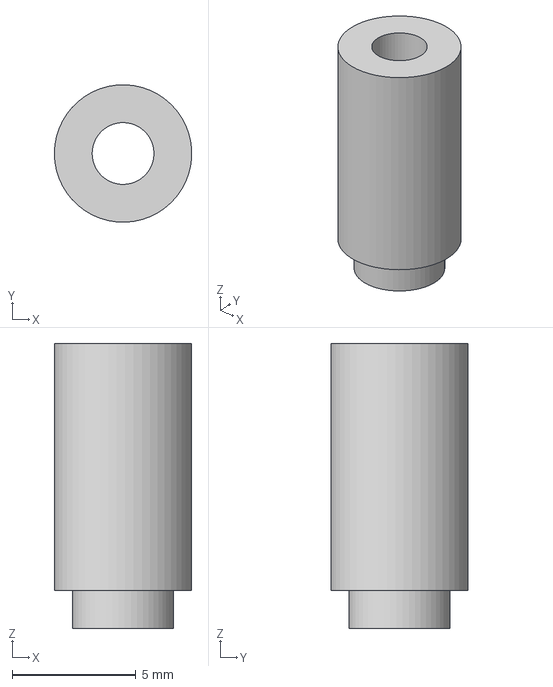
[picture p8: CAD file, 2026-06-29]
engineering/electronics/pcbs/CMAIN_PCB/kicad/EASYEDA_MODELS/EL-STANDOFF-003-M2.5x10.step
5.55 x 5.56 x 11.5 mm

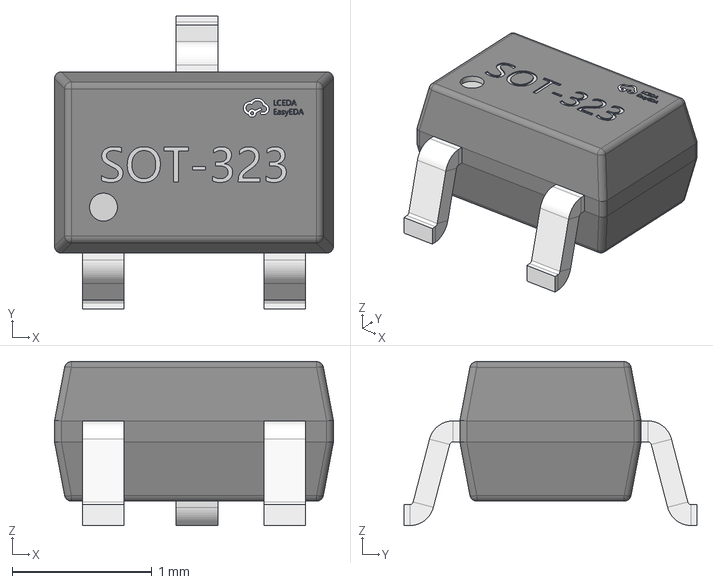
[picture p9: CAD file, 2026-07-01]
engineering/electronics/pcbs/CBC_PCB/kicad/EASYEDA_MODELS/SOT-323-3_L2.0-W1.3-H1.0-LS2.1-P1.30.step
2.00 x 2.10 x 1.18 mm

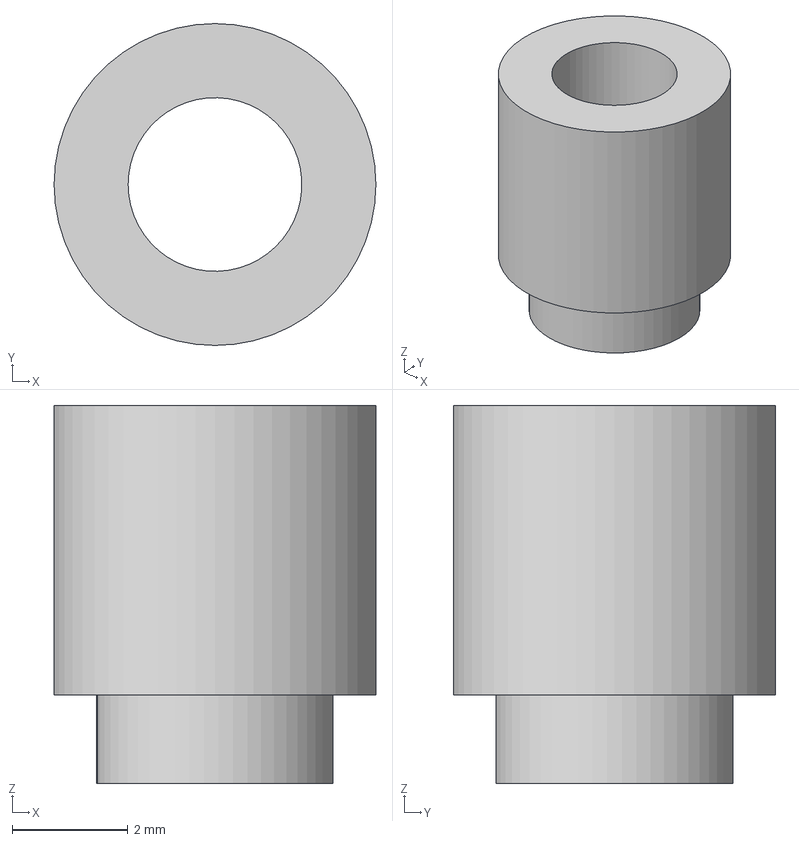
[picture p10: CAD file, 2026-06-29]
engineering/electronics/pcbs/CMAIN_PCB/kicad/EASYEDA_MODELS/EL-STANDOFF-002-M3x5.step
5.56 x 5.56 x 6.53 mm

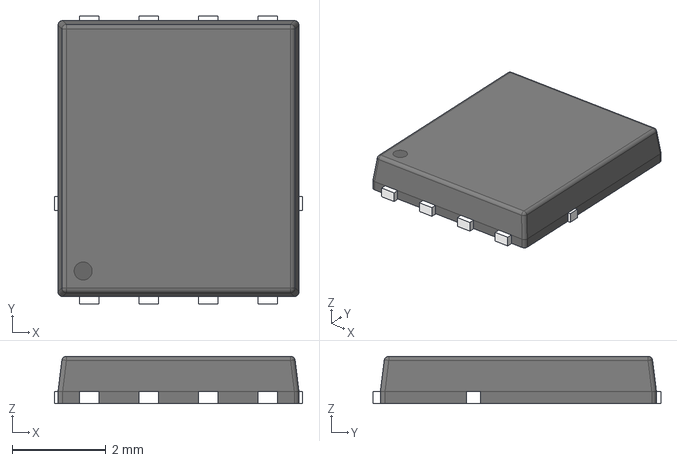
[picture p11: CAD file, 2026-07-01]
engineering/electronics/pcbs/CBC_PCB/kicad/EASYEDA_MODELS/PG-TDSON-8_L5.9-W5.2-P1.27-LS6.2-BL-EP.step
5.30 x 6.15 x 1.01 mm

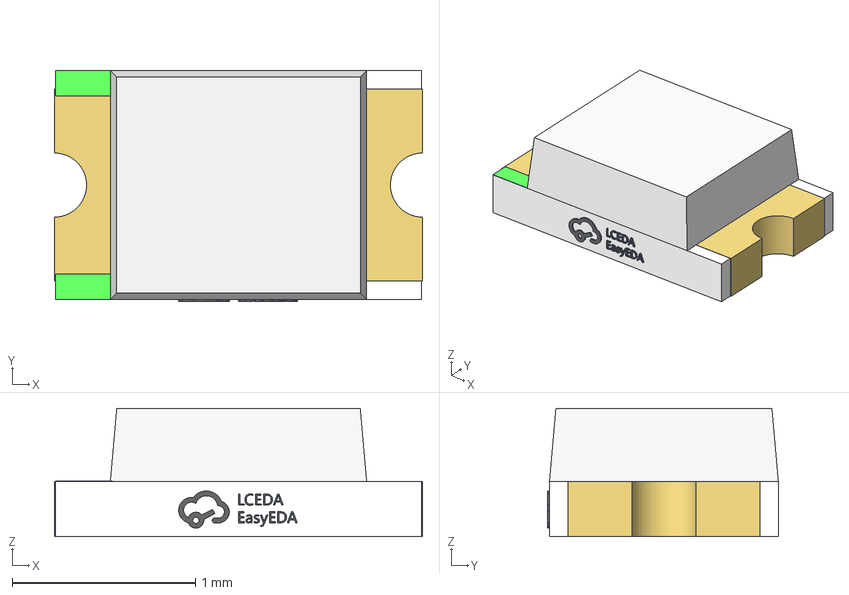
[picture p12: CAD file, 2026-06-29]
engineering/electronics/pcbs/CMAIN_PCB/kicad/EASYEDA_MODELS/LED-SMD_L2.0-W1.3-H0.8.step
2.01 x 1.26 x 0.701 mm

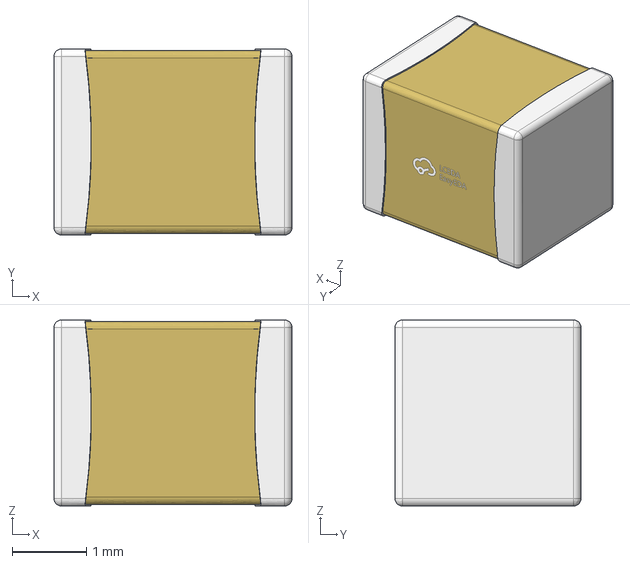
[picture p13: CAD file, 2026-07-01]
engineering/electronics/pcbs/CBC_PCB/kicad/EASYEDA_MODELS/C1210_L3.2-W2.5-H2.5.step
3.20 x 2.50 x 2.50 mm

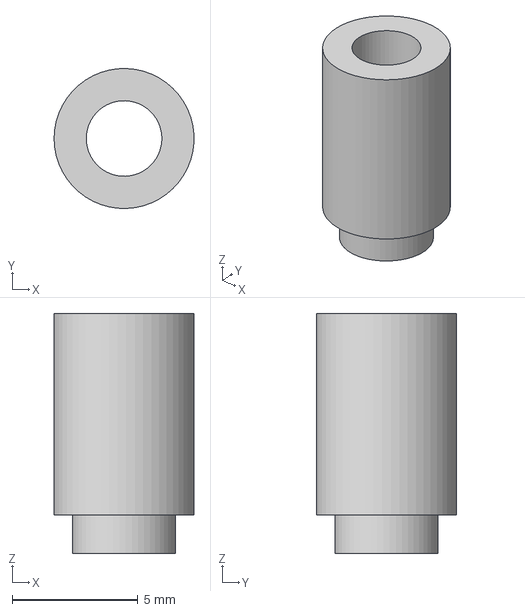
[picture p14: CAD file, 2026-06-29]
engineering/electronics/pcbs/CMAIN_PCB/kicad/EASYEDA_MODELS/EL-STANDOFF-001-M3x8.step
5.55 x 5.56 x 9.53 mm

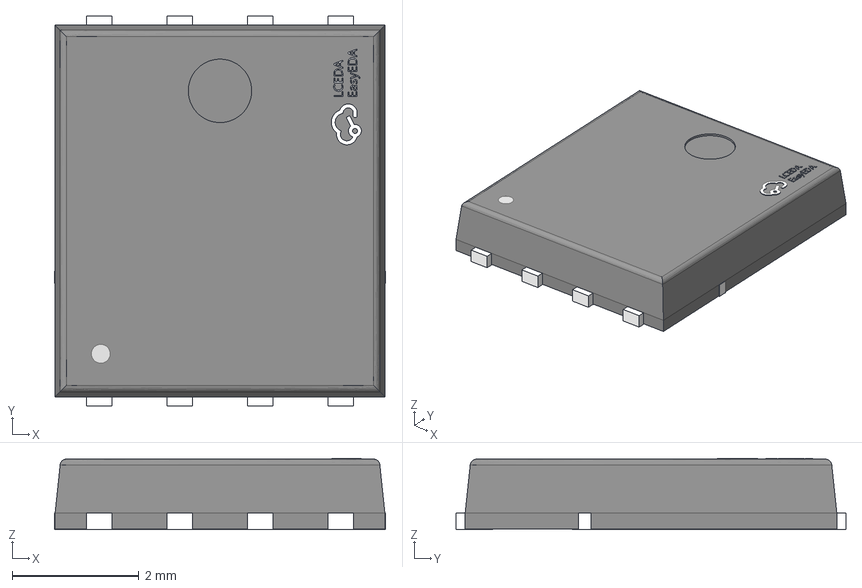
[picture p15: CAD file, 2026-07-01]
engineering/electronics/pcbs/CBC_PCB/kicad/EASYEDA_MODELS/DFN-8_L5.9-W5.2-P1.27-LS6.2-BL.step
5.22 x 6.15 x 1.12 mm

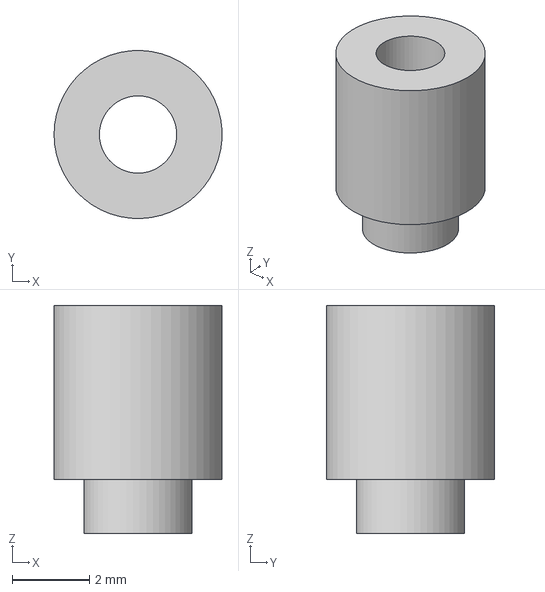
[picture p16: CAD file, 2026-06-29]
engineering/electronics/pcbs/CMAIN_PCB/kicad/EASYEDA_MODELS/EL-STANDOFF-004-M2x4.5.step
4.35 x 4.35 x 5.90 mm

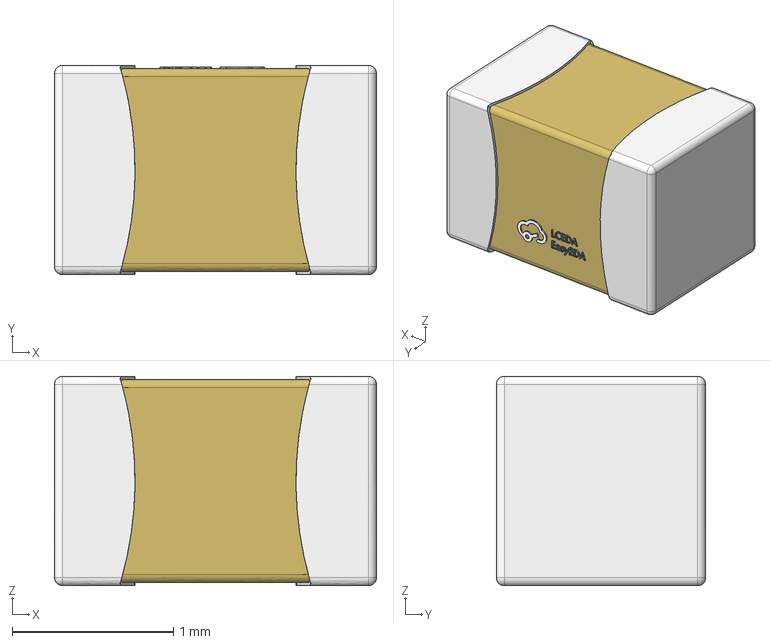
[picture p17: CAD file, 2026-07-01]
engineering/electronics/pcbs/CBC_PCB/kicad/EASYEDA_MODELS/C0805_L2.0-W1.3-H1.3.step
2.00 x 1.30 x 1.30 mm

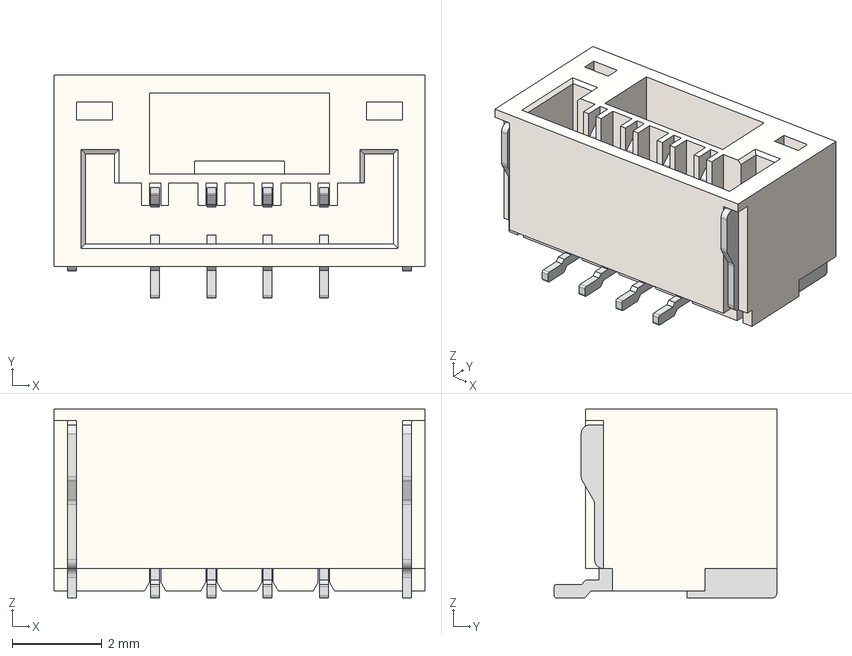
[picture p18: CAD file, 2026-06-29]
engineering/electronics/pcbs/CMAIN_PCB/kicad/EASYEDA_MODELS/CONN-TH_4P-P1.25_XUNPU_WAFER-GH1.25-4PLB.step
8.25 x 4.95 x 4.20 mm

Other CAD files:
engineering/electronics/pcbs/CBC_PCB/kicad/EASYEDA_MODELS/R0805_L2.0-W1.3-H0.6.step
engineering/electronics/pcbs/CBC_PCB/kicad/EASYEDA_MODELS/B08B-JWPF-SK-R.step
engineering/electronics/pcbs/CMAIN_PCB/kicad/EASYEDA_MODELS/CAP-SMD_L7.3-W4.3-RD_PA300LV227M0J.step
engineering/electronics/pcbs/CBC_PCB/kicad/EASYEDA_MODELS/IND-SMD_L5.0-W5.0-H4.0.step
engineering/electronics/pcbs/CBC_PCB/kicad/EASYEDA_MODELS/CAP-SMD_BD10.0-L10.3-W10.3-FD-LS11.0.step
engineering/electronics/pcbs/CBC_PCB/kicad/EASYEDA_MODELS/CAP-SMD_BD6.3-L6.6-W6.6-LS7.4-FD.step
engineering/electronics/pcbs/CBC_PCB/kicad/EASYEDA_MODELS/CRYSTAL-SMD_L3.2-W2.5_3225-8MHZ.step
engineering/electronics/pcbs/CBC_PCB/kicad/EASYEDA_MODELS/FUSE-SMD_L10.0-W5.0-H3.8.step
engineering/electronics/pcbs/CBC_PCB/kicad/EASYEDA_MODELS/IND-SMD_L6.0-W6.0-H4.5_SMNR6045.step
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

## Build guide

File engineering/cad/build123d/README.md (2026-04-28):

# build123d CAD

Parametric CAD source for Caribou build123d models.

## Suggested layout

- `src/` — Python source for models and assemblies.
- `exports/step/` — generated STEP files.
- `exports/stl/` — generated STL files.
- `reference/` — local reference geometry used by build scripts.

Add setup and export commands here once the first build123d model is committed.

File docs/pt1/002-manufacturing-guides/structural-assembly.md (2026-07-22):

---
title: Structural Assembly Guide
draft: true
---

# Structural Assembly Guide — PT1

**Status:** In progress  
**Applies to:** PT1 test frame

---

## 1. Overview

_Placeholder — describe the frame design, materials, and assembly approach._

## 2. Parts List

_Placeholder — BOM for the PT1 frame._

## 3. Tools Required

_Placeholder — list of tools and equipment needed._

## 4. Assembly Steps

_Placeholder — step-by-step frame build instructions._

## 5. Quality Checks

_Placeholder — inspection points, torque specs, alignment checks._

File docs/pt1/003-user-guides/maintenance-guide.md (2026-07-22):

---
title: Maintenance Guide
draft: true
---

# Maintenance Guide — PT1

**Status:** In progress  
**Applies to:** PT1 test frame

---

## 1. Overview

_Placeholder — describe the maintenance philosophy and intervals._

## 2. Pre-Flight Checks

_Placeholder — checklist before each flight._

## 3. Post-Flight Checks

_Placeholder — checklist after each flight._

## 4. Periodic Maintenance

_Placeholder — scheduled inspections, lubrication, fastener checks._

## 5. Common Issues and Fixes

_Placeholder — troubleshooting guide for known failure modes._

## 6. Storage

_Placeholder — battery storage, environmental requirements, long-term storage procedure._

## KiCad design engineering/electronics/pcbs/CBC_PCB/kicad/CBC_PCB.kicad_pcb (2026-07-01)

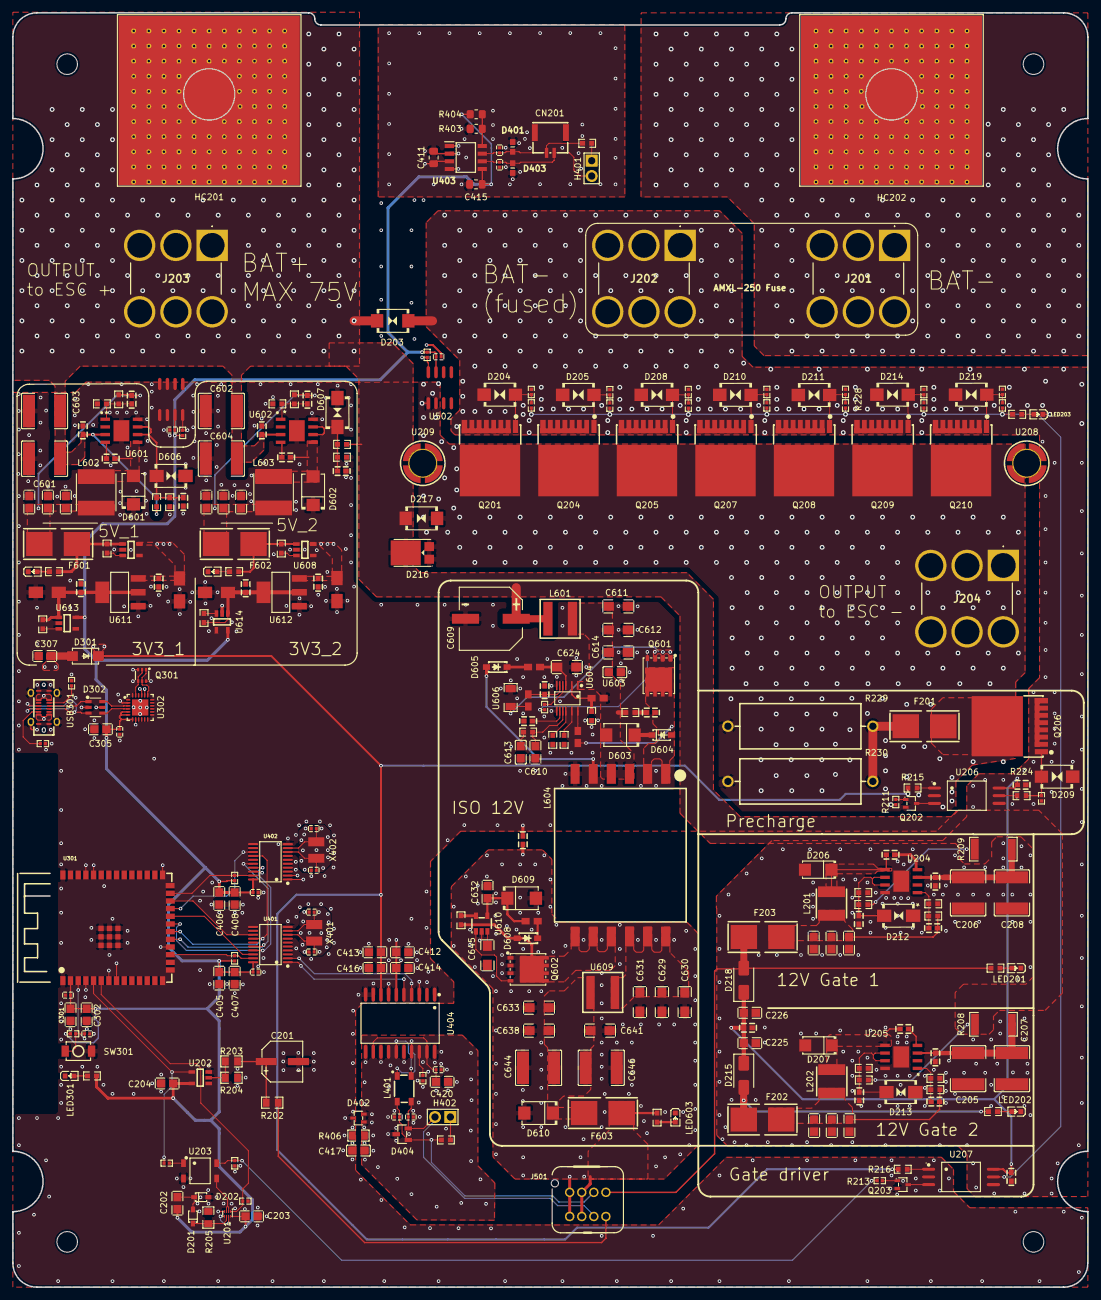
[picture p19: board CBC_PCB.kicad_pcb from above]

Board: 6 copper layers, 178.0 x 211.0 mm, 301 parts (0 on the bottom side), 148 nets.

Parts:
C201: 100uF; CAP-SMD_BD6.3-L6.6-W6.6-LS7.4-FD
C202, C632: 1uF; C0805
C203, C204, C302, C305, C307, C407, C408, C414, C416, C420: 10uF; C0805
C205, C206, C207, C208, C601, C602, C603, C604, C644, C646: 2.2uF; C2220
C209, C210, C211, C212, C213, C214, C215, C216, C223, C224, C227, C605, C606, C607, C608, C616, C617, C626, C627, C634, C635, C639, C640: 100nF; C0603
C217, C218, C219, C220, C221, C222, C225, C226, C301, C405, C406, C412, C413, C618, C619, C620, C621, C622, C623: 4.7uF; C0805
C303: 1uF; C0402
C304, C306, C409, C410, C421, C501, C502: 100nF; C0402
C401, C402, C403, C404: 22pF; C0402
C411, C415: 100nF; C_0805_2012Metric_Pad1.18x1.45mm_HandSolder
C417: 100pF; C0805
C418, C419, C422, C423: 220pF; C0402
C609: 47uF; CAP-SMD_BD10.0-L10.3-W10.3-FD-LS11.0
C610: 470pF; C0805
C611, C612, C614, C624, C645: 4.7uF; C1206
C613: 33nF; C0805
C615: 220nF; C0603
C625: 47pF; C0603
C628: 4.7nF; C0603
C629, C630, C631, C633, C638, C641: 47uF; C1206
C636, C637, C642, C643: 10uF; CAP-SMD_L3.5-W2.8-R-RD
CN201: CONN-SMD_A1257WV-S-2P
D201, D202: SOD-323_L1.8-W1.3-LS2.5-RD
D203, D217: SMBJ78CA; SMB_L4.3-W3.6-LS5.4-BI
D204, D205, D208, D209, D210, D211, D214, D219: SMB_L4.6-W3.6-LS5.4-BI
D206, D207: SMA_L4.3-W2.6-LS5.2-RD
D212, D213, D606, D607: SMB_L4.6-W3.6-LS5.3-BI
D215, D218: SS34; D_SMA
D216: FSV10150V; C719814_TO-277A_L5_9-W4_4-LS6_5-TR
D301: SMA_L4.3-W2.6-LS5.0-FD
D302: SOT-23-6_L2.9-W1.6-P0.95-LS2.8-BL
D401, D403: PESD0603-240; DIONC1608X55N
D402: SOT-323-3_L2.0-W1.3-P1.30-LS2.1-BR
D404: SOT-23-3_L2.9-W1.3-P1.90-LS2.4-BL-2
D601, D602, D603, D609, D610: SMB_L4.6-W3.6-LS5.3-RD
D604: SOD-123FL_L2.8-W1.8-LS3.8-RD
D605, D608: SOD-123_L2.7-W1.6-LS3.7-RD-1
F201, F603: 0154005.DR; FUSE-SMD_L9.8-W5.1
F202, F203, F601, F602: FUSE-SMD_L9.8-W5.1
H401, H402: HDR-TH_2P-P2.54-V-M
HC201, HC202: C90D_PAD
J201, J202, J203, J204: AMT0650009DB0000G
J501: B08B-JWPF-SK-R
L201, L202: 33uH; IND-SMD_L5.0-W5.0-P3.60_SMNR5040
L401: FILTER-SMD_4P-L4.5-W3.2_ACT45B-510-2P
L601: 22uH; IND-SMD_L6.6-W6.4
L602, L603: 33uH; IND-SMD_L6.0-W6.0_SMNR6045
L604: 20.5uH; XFMR-SMD_12P-L22.1-W21.8-P3.00-LS29.2-BL
LED201, LED202, LED203, LED301, LED601, LED602, LED603: LED0603-RD
Q201, Q205, Q206, Q207, Q208, Q209, Q210: TOLL-8_L10.4-W9.9-P1.20-LS11.7-BL
Q202, Q203: LMUN5235T1G; C2846922_SOT-323-3_L2_0-W1_3-P1_30-LS2_1-BR
Q204: SP015N03BGHTO; TOLL-8_L10.4-W9.9-P1.20-LS11.7-BL
Q301: SC-70-6_L2.2-W1.3-P0.65-LS2.1-BR
Q601, Q602: DFN-8_L5.9-W5.2-P1.27-LS6.2-BL
R201, R207, R212, R217, R223, R226, R227, R235, R237, R242, R301, R401, R402: 10kΩ; R0402
R202: 15kΩ; R0805
R203: 120kΩ; R0805
R204: 36kΩ; R0805
R205: 10kΩ; R0805
R206: 330Ω; R0402
R208, R209: 10Ω; R2512
R210, R214, R218, R225, R228, R236, R240: 100Ω; C25076_R0402
R211, R213: 0; C106231_R0402
R215, R216: 300; C114617_R0603
R219, R221: 590K, 0603; R0603
R220, R222, R232, R234, R605, R607, R614, R616: 10kΩ; R0603
R224: 20; C125758_R0603
R229, R230: 33Ω; RES-TH_BD7.5-L20.0-P24.00-D1.0
R231, R233, R613, R615: 140kΩ; R0603
R238, R239, R241, R625: 1.8kΩ; R0603
R302: 39Ω; R0603
R303, R304: 5.1kΩ; R0402
R403: 0R; R_0805_2012Metric_Pad1.20x1.40mm_HandSolder
R404: 10K; R_0805_2012Metric_Pad1.20x1.40mm_HandSolder
R405, R408: 120Ω; R0603
R406: 1MΩ; R0805
R407, R611: 0Ω; R0402
R501, R502: 4.7kΩ; R0402
R601: 6.04kΩ; R0603
R602: 60.4kΩ; R0603
R603: 7.5kΩ; R0603
R604, R606: 240kΩ; R0603
R608: 1.2MΩ; R0805
R609: 51kΩ; R0603
R610: 160kΩ; R0805
R612: 68Ω; R0805
R617, R623: 3Ω; R0805
R618, R619, R621, R626, R627: 100Ω; R0603
R620, R622: 390Ω; R0603
R624: 2.37kΩ; R0603
SW301: SW-SMD_L3.9-W3.0-P4.45
U201: 74LVC2G02HK3-7; UDFN-8_L1.5-W1.0-P0.35-BL
U202: 74LVC1G17W5-7; SOT-25-5_L3.0-W1.8-P0.95-LS3.0-BL
U203: CPC1106NTR; SOP-4_L4.1-W3.8-P2.54-LS6.1-BL
U204, U205, U601, U602: MP9486GN-Z; SOIC-8EP_MP9486_MNP
U206, U207: ICPL-314P-500EAXW; C42432174_SOP-6_L6_8-W4_6-P1_27-LS11_7-BL
U208, U209: BSMTSOM330BTR; SMD_BD6.0-D4.2
U301: 2.4GHz; WIRELM-SMD_ESP32-S3-WROOM-1
U302: QFN-24_L4.0-W4.0-P0.50-BL-EP2.7
U401, U402: TSSOP-20_L6.5-W4.4-P0.65-LS6.4-BL
U403: TJA1049T/3J; SOIC127P600X175-8N
U404: ADM3053BRWZ-REEL7; SOIC-20_L13.0-W7.6-P1.27-LS10.3-BL
U501, U502: SOIC-8_L4.9-W3.9-P1.27-LS6.0-BL
U603: 1uF; C0805
U604: MSOP-16_12P-L4.0-W3.0-P0.50-LS4.9-BL
U605: 120pF; C0603
U606: 10mΩ; R1206
U607, U608, U613, U614: MAX40203AUK+T; MAX40203AUK_T_SOT-23-5
U609: 1uH; IND-SMD_L6.6-W6.4_XAL6060-103ME
U610: TSOT-23-5_L2.9-W1.6-P0.95-LS2.8-BR
U611, U612: SOT-223-3_L6.5-W3.4-P2.30-LS7.0-BR
USB301: USB-C-SMD_TYPEC-303-ACP16
X401, X402: 16MHz; CRYSTAL-SMD_L3.2-W2.5_3225-8MHZ

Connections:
12V_GATE_P1: C215.2, C217.2, C219.2, C221.2, F203.1, L201.2, R219.2
12V_GATE_P2: C216.2, C218.2, C220.2, C222.2, F202.1, L202.2, R221.2
12V_GATE_V: C213.2, C214.2, C225.2, C226.2, C227.2, D215.1 (K), D218.1 (K), U206.6 (VCC), U207.6 (VCC)
12V_ISOLATED: F603.2, J501.3, J501.4, R625.2
12V_Supply: D218.2 (A), F203.2, J501.8, R238.1
12V_TRIGGER_SIG: J501.7, R202.1
+3V3: C202.2, C203.2, C204.2, C301.2, C302.2, C304.2, C305.2, C306.2, C405.2, C406.2, C407.2, C408.2, C409.2, C410.2, C412.2, C414.2, C415.1, C501.2, C502.2, R301.2, R302.2, R401.2, R402.2, R404.1, R501.2, R502.2, U201.8 (VCC), U202.5 (VCC), U301.2 (3V3), U302.5 (VIO), U302.6 (VDD), U302.7 (REGIN), U401.20 (VDD), U402.20 (VDD), U403.5 (VIO), U404.6 (VIO), U501.3 (VDD), U502.3 (VDD), U613.5 (OUT), U614.5 (OUT)
+3V3_P1: C634.1, C636.1, R626.1, U611.2 (VOUT), U611.4 (VOUT), U613.1 (VDD)
+3V3_P2: C635.1, C637.1, R627.1, U612.2 (VOUT), U612.4 (VOUT), U614.1 (VDD)
+5V: C411.2, C413.2, C416.2, C639.1, C640.1, C642.1, C643.1, D301.2 (K), R215.1, R216.1, U403.3 (VDD), U404.8 (VCC), U607.5 (OUT), U608.5 (OUT), U611.3 (VIN), U612.3 (VIN)
+5V_P1: C616.2, C618.2, C620.2, C622.2, F601.1, L602.2, R604.2
+5V_P2: C617.2, C619.2, C621.2, C623.2, F602.1, L603.2, R606.2
/CAN SECTION/RXD: U402.2 (RXCAN), U403.4 (RX)
/CAN SECTION/RXD2: U401.2 (RXCAN), U404.4 (RXD)
/CAN SECTION/TXD: U402.1 (TXCAN), U403.1 (TX)
/CAN SECTION/TXD2: U401.1 (TXCAN), U404.5 (TXD)
/ESP32 SECTION/D+: D302.6, U302.3 (D+)
/ESP32 SECTION/D-: D302.4, U302.4 (D-)
/ESP32 SECTION/DP_N: D302.3, USB301.A7 (DN1), USB301.B7 (DN2)
/ESP32 SECTION/DP_P: D302.1, USB301.A6 (DP1), USB301.B6 (DP2)
/ESP32 SECTION/DTR: Q301.2 (B), Q301.4 (E), U302.23 (DTR)
/ESP32 SECTION/GPIO0: Q301.3 (C), U301.27 (IO0)
/ESP32 SECTION/RESET: C303.2, Q301.6 (C), R301.1, SW301.1, U301.3 (EN)
/ESP32 SECTION/RTS: Q301.1 (E), Q301.5 (B), U302.19 (RTS)
/ESP32 SECTION/RXD0: U301.36 (RXD0), U302.21 (TXD)
/ESP32 SECTION/TXD0: U301.37 (TXD0), U302.20 (RXD)
/POWER SECTION/MOSFET_CONTROL_SIGNAL: R207.2, R213.1, U203.4 (Load)
/POWER SECTION/SWITCHED_GATE_V: R210.1, R214.1, R218.1, R225.1, R228.1, R236.1, R240.1, R241.1, U207.5 (VO)
CANH_BAT: C418.2, CN201.1, D401.1 (K), R405.2, U403.7 (CANH)
CANH_DRONE: C422.2, D404.1, J501.6, L401.2, R408.2
CANL_BAT: C419.1, CN201.2, D403.1 (K), H401.2, U403.6 (CANL)
CANL_DRONE: C423.1, D404.2, H402.2, J501.5, L401.3
CS#1: U301.18 (IO10), U402.18 (CS#)
CS#2: U301.22 (IO14), U401.18 (CS#)
ESP_ENABLE_SIGNAL: R201.2, U201.1 (1A), U301.6 (IO6)
GND: C201.2, C203.1, C204.1, C301.1, C302.1, C303.1, C304.1, C305.1, C306.1, C307.1, C401.1, C402.1, C403.1, C404.1, C405.1, C406.1, C407.1, C408.1, C409.1, C410.1, C411.1, C412.1, C413.1, C414.1, C415.2, C416.1, C417.1, C418.1, C419.2, C501.1, C502.1, C601.1, C602.1, C603.1, C604.1, C605.2, C606.2, C609.2, C610.1, C611.1, C612.1, C613.2, C614.1, C615.1, C618.1, C619.1, C620.1, C621.1, C622.1, C623.1, C624.1, C625.1, C626.1, C627.1, C628.1, C634.2, C635.2, C636.2, C637.2, C639.2, C640.2, C642.2, C643.2, D202.2 (A), D216.1 (A), D216.2 (A), D217.2, D302.2, D401.2 (A), D402.3, D403.2 (A), D601.1 (A), D602.1 (A), D606.1 (K), D607.1 (K), J204.1, J204.2, J204.3, J204.4, J204.5, J204.6, L604.6, LED301.1 (K), LED601.1 (K), LED602.1 (K), Q201.9 (D), Q202.2 (E), Q203.2 (E), Q204.9 (D), Q205.9 (D), Q207.9 (D), Q208.9 (D), Q209.9 (D), Q210.9 (D), R201.1, R204.1, R205.1, R207.1, R229.2, R230.2, R303.1, R304.1, R403.1, R406.1, R601.1, R602.1, R605.1, R607.1, R609.1, R614.1, R616.1, SW301.2, U201.4 (GND), U202.3 (GND), U203.2 (-Control), U301.1 (GND), U301.40 (GND), U301.41 (GND), U302.2 (GND), U302.25 (EPAD), U401.10 (VSS), U402.10 (VSS), U403.2 (GND), U404.1 (GND1), U404.3 (GND1), U404.7 (GND1), U404.9 (GND1), U404.10 (GND1), U501.5 (GND), U502.5 (GND), U601.8 (GND), U602.8 (GND), U603.2, U604.8 (GND), U604.9 (GND), U606.1, U607.2 (GND), U608.2 (GND), U611.1 (GND), U612.1 (GND), U613.2 (GND), U614.2 (GND), USB301.1 (GND), USB301.2 (GND), USB301.3 (GND), USB301.4 (GND), USB301.A1 (GND), USB301.A12 (GND), USB301.B1 (GND), USB301.B12 (GND)
GNDE: C628.2, C629.1, C630.1, C631.1, C632.1, C633.1, C638.1, C641.1, C644.1, C645.1, C646.1, D609.2 (A), D610.2, J501.1, J501.2, LED603.1 (K), Q602.1 (S), U610.2 (GND)
GND_CD: C417.2, C420.1, C421.1, C422.1, C423.2, D402.1, D402.2, D404.3, R406.2, R407.2, U404.11 (GND2), U404.13 (GND2), U404.16 (GND2), U404.20 (GND2)
H_PWR-IN: C601.2, C602.2, C603.2, C604.2, C605.1, C606.1, C609.1, D203.1, D216.3 (K), D217.1, HC201.1 (1_1), J203.1, J203.2, J203.3, J203.4, J203.5, J203.6, L601.1, R208.2, R209.2, R231.2, R233.2, R613.2, R615.2, U601.3 (VIN), U602.3 (VIN)
H_PWR-IN-: C205.1, C206.1, C207.1, C208.1, C209.2, C210.2, C213.1, C214.1, C217.1, C218.1, C219.1, C220.1, C221.1, C222.1, C223.1, C224.1, C225.1, C226.1, C227.1, D203.2, D204.1, D205.1, D206.2 (A), D207.2 (A), D208.1, D209.1, D210.1, D211.1, D212.1 (K), D213.1 (K), D214.1, D219.1, J202.1, J202.2, J202.3, J202.4, J202.5, J202.6, LED201.1 (K), LED202.1 (K), LED203.1 (K), Q201.2 (S), Q201.3 (S), Q201.4 (S), Q201.5 (S), Q201.6 (S), Q201.7 (S), Q201.8 (S), Q204.2 (S), Q204.3 (S), Q204.4 (S), Q204.5 (S), Q204.6 (S), Q204.7 (S), Q204.8 (S), Q205.2 (S), Q205.3 (S), Q205.4 (S), Q205.5 (S), Q205.6 (S), Q205.7 (S), Q205.8 (S), Q206.2 (S), Q206.3 (S), Q206.4 (S), Q206.5 (S), Q206.6 (S), Q206.7 (S), Q206.8 (S), Q207.2 (S), Q207.3 (S), Q207.4 (S), Q207.5 (S), Q207.6 (S), Q207.7 (S), Q207.8 (S), Q208.2 (S), Q208.3 (S), Q208.4 (S), Q208.5 (S), Q208.6 (S), Q208.7 (S), Q208.8 (S), Q209.2 (S), Q209.3 (S), Q209.4 (S), Q209.5 (S), Q209.6 (S), Q209.7 (S), Q209.8 (S), Q210.2 (S), Q210.3 (S), Q210.4 (S), Q210.5 (S), Q210.6 (S), Q210.7 (S), Q210.8 (S), R212.1, R217.1, R220.1, R222.1, R223.1, R226.1, R227.1, R232.1, R234.1, R235.1, R237.1, R242.1, U204.8 (GND), U205.8 (GND), U206.4 (VSS), U207.4 (VSS)
H_PWR-IN--PREFUSE: HC202.1 (1_1), J201.1, J201.2, J201.3, J201.4, J201.5, J201.6
INT#1: U301.23 (IO21), U402.13 (INT#)
INT#2: U301.24 (IO47), U401.13 (INT#)
INTVCC: C624.2, R612.1, U604.5 (INTVCC)
MISO: U301.21 (IO13), U401.17 (SO), U402.17 (SO)
MOSI: U301.19 (IO11), U401.16 (SI), U402.16 (SI)
unnamed: C613.1, R603.1
unnamed: C629.2, C630.2, C631.2, L604.10, L604.11, L604.12, U609.1
unnamed: C633.2, C638.2, C641.2, C644.2, C646.2, D610.1, F603.1, U609.2
unnamed: C202.1, D201.2 (A), D202.1 (K)
unnamed: D201.1 (K), R205.2, U201.6 (2B)
unnamed: C211.1, D206.1 (K), L201.1, U204.5 (SW)
unnamed: C212.1, D207.1 (K), L202.1, U205.5 (SW)
unnamed: C223.2, D212.2 (A), R231.1, R232.2, U204.6 (DIM), U204.7 (EN)
unnamed: C224.2, D213.2 (A), R233.1, R234.2, U205.6 (DIM), U205.7 (EN)
unnamed: D215.2 (A), F202.2, R239.1
unnamed: C607.1, D601.2 (K), L602.1, U601.5 (SW)
unnamed: C608.1, D602.2 (K), L603.1, U602.5 (SW)
unnamed: C611.2, C612.2, C614.2, D603.2 (A), L601.2, L604.3, L604.4, R608.2, R618.2, U603.1, U604.1 (VIN)
unnamed: D603.1 (K), D604.1 (K)
unnamed: D604.2 (A), L604.1, L604.2, Q601.3 (D), R610.2, U605.1
unnamed: D605.2 (A), L604.5
unnamed: D605.1 (C), R612.2
unnamed: C626.2, D606.2 (A), R613.1, R614.2, U601.6 (DIM), U601.7 (EN)
unnamed: C627.2, D607.2 (A), R615.1, R616.2, U602.6 (DIM), U602.7 (EN)
unnamed: D608.2 (A), L604.7, L604.8, L604.9, Q602.3 (D), R624.1
unnamed: D608.1 (C), R623.1
unnamed: C632.2, D609.1 (K), R623.2, U610.4 (VCC)
unnamed: F201.2, R229.1, R230.1
unnamed: H401.1, R405.1
unnamed: H402.1, R408.1
unnamed: LED201.2 (A), R238.2
unnamed: LED202.2 (A), R239.2
unnamed: LED203.2 (A), R241.2
unnamed: LED301.2 (A), R302.1
unnamed: LED601.2 (A), R620.2
unnamed: LED602.2 (A), R622.2
unnamed: LED603.2 (A), R625.1
unnamed: D204.2, Q201.1 (G), R210.2, R212.2
unnamed: Q202.1 (B), R211.2
unnamed: Q202.3 (C), U206.3 (C)
unnamed: Q203.1 (B), R213.2
unnamed: Q203.3 (C), U207.3 (C)
unnamed: D205.2, Q204.1 (G), R214.2, R217.2
unnamed: D208.2, Q205.1 (G), R218.2, R223.2
unnamed: F201.1, Q206.9 (D)
unnamed: D209.2, Q206.1 (G), R224.2, R226.2
unnamed: D210.2, Q207.1 (G), R225.2, R227.2
unnamed: D211.2, Q208.1 (G), R228.2, R235.2
unnamed: D214.2, Q209.1 (G), R236.2, R237.2
unnamed: D219.2, Q210.1 (G), R240.2, R242.2
unnamed: Q601.2 (G), R611.2
unnamed: Q601.1 (S), R617.2, U606.2
unnamed: Q602.2 (G), U610.1 (GATE)
unnamed: R618.1, U605.2
unnamed: U201.2 (1B), U201.3 (2Y), U203.3 (Load)
unnamed: U201.5 (2A), U201.7 (1Y)
unnamed: R203.1, R204.2, U202.2 (A)
unnamed: R206.1, U203.1 (+Control)
unnamed: C211.2, U204.4 (BST)
unnamed: C215.1, R219.1, R220.2, U204.1 (FB)
unnamed: C206.2, C208.2, C209.1, R209.1, U204.3 (VIN)
unnamed: C212.2, U205.4 (BST)
unnamed: C216.1, R221.1, R222.2, U205.1 (FB)
unnamed: C205.2, C207.2, C210.1, R208.1, U205.3 (VIN)
unnamed: R215.2, U206.1 (A)
unnamed: R224.1, U206.5 (VO)
unnamed: R216.2, U207.1 (A)
unnamed: C401.2, U401.9 (OSC1), X401.1 (OSC1)
unnamed: C403.2, U401.8 (OSC2), X401.2 (OSC2)
unnamed: C402.2, U402.9 (OSC1), X402.1 (OSC1)
unnamed: C404.2, U402.8 (OSC2), X402.2 (OSC2)
unnamed: R403.2, R404.2, U403.8 (STB)
unnamed: L401.1, U404.17 (CANH)
unnamed: L401.4, U404.15 (CANL)
unnamed: R407.1, U404.18 (RS)
unnamed: C420.2, C421.2, U404.12 (VISOOUT), U404.19 (VISOIN)
unnamed: C607.2, U601.4 (BST)
unnamed: C616.1, R604.1, R605.2, U601.1 (FB)
unnamed: C608.2, U602.4 (BST)
unnamed: C617.1, R606.1, R607.2, U602.1 (FB)
unnamed: R608.1, R609.2, U604.3 (EN/UVLO)
unnamed: R611.1, U604.6 (GATE)
unnamed: R610.1, U604.16 (RFB)
unnamed: R601.2, U604.14 (RREF)
unnamed: C625.2, R617.1, U604.7 (SENSE)
unnamed: C615.2, U604.10 (SS)
unnamed: R602.2, U604.12 (TC)
unnamed: C610.2, R603.2, U604.11 (VC)
unnamed: R619.2, U607.3 (EN)
unnamed: F601.2, R619.1, R620.1, U607.1 (VDD)
unnamed: R621.2, U608.3 (EN)
unnamed: F602.2, R621.1, R622.1, U608.1 (VDD)
unnamed: R624.2, U610.5 (DRAIN)
unnamed: C645.2, U610.3 (INTVCC)
unnamed: R626.2, U613.3 (EN)
unnamed: R627.2, U614.3 (EN)
unnamed: R303.2, USB301.A5 (CC1)
unnamed: R304.2, USB301.B5 (CC2)
OUTPUT: C201.1, R202.2, R203.2
PRECHARGE_ESP_SIGNAL: R211.1, U301.4 (IO4)
RESET1: R402.1, U301.25 (IO48), U402.19 (RESET#)
RESET2: R401.1, U301.17 (IO9), U401.19 (RESET#)
SCHMITT_OUT: R206.2, U202.4 (Y), U301.5 (IO5)
SCK: U301.20 (IO12), U401.14 (SCK), U402.14 (SCK)
TEMP1_DQ: R501.1, U301.8 (IO15), U501.4 (DQ)
TEMP2_DQ: R502.1, U301.7 (IO7), U502.4 (DQ)
USBV: C307.2, D301.1 (A), D302.5, U302.8 (VBUS), USB301.A4 (VBUS), USB301.A9 (VBUS), USB301.B4 (VBUS), USB301.B9 (VBUS)

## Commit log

2026-03-30 docs: add project README
    Covers project overview, mission profile, design philosophy,
    phase breakdown, governance, deliverables, and regulatory strategy.
    Based on the AIP-006 proposal and Project Caribou forum discussion:
    https://dao.arrowair.com/t/project-caribou-discussion-heavy-lift-hexacopter/150
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2026-04-01 docs: add PT1 documentation structure
    - docs/pt1/001-engineering-report/engineering-report.md
    - docs/pt1/002-manufacturing-guides/frame-assembly.md
    - docs/pt1/003-user-guides/maintenance-guide.md
    All placeholder content, ready to fill in.
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2026-05-05 docs: update C90D PCB readme from issue
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2026-05-05 docs: add clean CMAIN KiCad fork
    [CAN circuit.kicad_sch, CMAIN_PCB.kicad_pcb, CMAIN_PCB.kicad_sch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]
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2026-05-07 Import linked CMAIN PCB layout
    [CAN circuit.kicad_sch, CMAIN_PCB.kicad_sch, ETHERNET.kicad_sch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]
2026-05-19 Add initial CBC PCB KiCad layout
    [CAN SECTION.kicad_sch, CBC_PCB.kicad_pcb, CBC_PCB.kicad_sch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]
2026-05-19 fix: restore CBC schematic library nicknames
    [CAN SECTION.kicad_sch, ESP32 SECTION.kicad_sch, PERIPHERALS.kicad_sch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]
2026-05-19 fix: qualify CBC connector footprint refs
    [PERIPHERALS.kicad_sch, POWER REGULATOR.kicad_sch, POWER SECTION.kicad_sch]
2026-05-23 fix: align CBC schematic connections to grid
    [POWER SECTION.kicad_sch]
2026-05-23 fix: assign CBC imported symbol pin types
    [CAN SECTION.kicad_sch, ESP32 SECTION.kicad_sch, PERIPHERALS.kicad_sch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]
2026-05-23 fix: clean CBC KiCad library references
    [PERIPHERALS.kicad_sch]
2026-05-23 fix: make CBC EasyEDA footprint library loadable
2026-05-23 fix: add CBC peripheral sensor power flag
    [PERIPHERALS.kicad_sch]
2026-05-23 fix: include updated CBC power section
    [POWER SECTION.kicad_sch]
2026-05-23 docs: capture CBC schematic review follow-ups
    [CAN SECTION.kicad_sch, ESP32 SECTION.kicad_sch, PERIPHERALS.kicad_sch]
2026-05-23 electronics: update CBC redundant power regulators
    [POWER REGULATOR.kicad_sch, POWER SECTION.kicad_sch]
2026-05-24 fix: align CBC schematics to KiCad grid
    [CAN SECTION.kicad_sch, CBC_PCB.kicad_sch, ESP32 SECTION.kicad_sch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]
2026-05-25 electronics: integrate CBC PCB updates
    [CAN SECTION.kicad_sch, CBC_PCB.kicad_pcb, ESP32 SECTION.kicad_sch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]
2026-05-25 electronics: update CBC PCB and crystal parts
    [CAN SECTION.kicad_sch, CBC_PCB.kicad_pcb, CRYSTAL-SMD_L3.2-W2.5_3225-8MHZ.step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]
2026-05-26 electronics: integrate CBC PCB footprint updates
    [CBC_PCB.kicad_pcb, POWER REGULATOR.kicad_sch, WIRELM-SMD_ESP32-S3-WROOM-1.step]
2026-05-26 electronics: fix CBC footprint component types
    [CBC_PCB.kicad_pcb]
2026-05-26 electronics: fix CBC 3D model references
    [CBC_PCB.kicad_pcb]
2026-05-26 electronics: clear CBC silkscreen copper warnings
    [CBC_PCB.kicad_pcb]
2026-05-26 electronics: integrate final CBC PCB routing update
    [CBC_PCB.kicad_pcb]
2026-06-01 electronics: update CMAIN and CBC PCB files
    [CAN SECTION.kicad_sch, CBC_PCB.kicad_pcb, CMAIN_PCB.kicad_sch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]
2026-06-02 electronics: integrate C90D PCB v1.1 files
    [C90D_PCB.kicad_pcb, C90D_PCB.kicad_sch]
2026-06-02 electronics: integrate June PCB updates
    [C90D_PCB.step, CBC_PCB.kicad_pcb, CMAIN_PCB.kicad_sch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]
2026-06-02 electronics: clean up CMAIN local libraries
    [CAN circuit.kicad_sch, CMAIN_PCB.kicad_pcb, CMAIN_PCB.kicad_sch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]
2026-06-02 electronics: snap CMAIN schematic endpoints to grid
    [CMAIN_PCB.kicad_sch, power_supply.kicad_sch]
2026-06-04 feat: integrate June PCB updates
    [CBC_PCB.kicad_pcb, CMAIN_PCB.kicad_sch, PERIPHERALS.kicad_sch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]
2026-06-12 electronics: update CMAIN PCB from June layout
    [CAN circuit.kicad_sch, CMAIN_PCB.kicad_pcb, CMAIN_PCB.kicad_sch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]
2026-06-12 electronics: resolve available CMAIN 3D models
    [AT13-08PA-BM01.stp, C1206_L3.2-W1.6-H1.3.step, CMAIN_PCB.kicad_pcb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]
2026-06-12 electronics: add available CMAIN JLC 3D models
    [CAP-SMD_L7.3-W4.3-RD_PA300LV227M0J.step, CAP-TH_BD10.0-P5.00-D0.6-FD_2.step, CAP-TH_D8.0-H8.0-P3.50.step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]
2026-06-12 electronics: map CMAIN standard 3D model refs
    [CMAIN_PCB.kicad_pcb, SCREW-SMD_BD4.4-D2.8-H4.5.step, SMD_BD5.6-L5.6-W5.6-D4.1.step]
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2026-06-15 Revert "electronics: vendor CMAIN EasyEDA footprints"
    This reverts commit 9d702adc658192e84b57025cf413e62d678808d8.
2026-06-15 electronics: shorten CMAIN footprint filenames for Windows
    [CAN circuit.kicad_sch, CMAIN_PCB.kicad_pcb, CMAIN_PCB.kicad_sch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]
2026-06-15 electronics: integrate CMAIN STEP updates and consolidate footprints
    [CAN circuit.kicad_sch, CMAIN_PCB.kicad_pcb, CMAIN_PCB.kicad_sch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]
2026-06-15 Fix CMAIN schematic embedded symbol name
    [CMAIN_PCB.kicad_sch]
2026-06-15 Resolve CMAIN ERC warnings
    [CMAIN_PCB.kicad_sch, power_supply.kicad_sch]
2026-06-15 Apply CMAIN PCB routing rule classes
    [CMAIN_PCB.kicad_pcb]
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2026-06-16 Update CMAIN PCB routing from latest archive
    Import Julius's latest CMAIN KiCad update, excluding local .history and backup archives. Remap undefined Rescue footprint graphics to F.Fab so KiCad CLI can load the board, and add KiCad ERC/DRC repo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
    [CAN circuit.kicad_sch, CMAIN_PCB.kicad_pcb, CMAIN_PCB.kicad_sch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]
2026-06-18 Clean up CMAIN part value fields
    [CAN circuit.kicad_sch, CMAIN_PCB.kicad_sch, Emergency_cutoff.kicad_sch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]
2026-06-23 fix(cmain): import KiCad updates with native libs
    [CAN circuit.kicad_sch, CMAIN_PCB.kicad_pcb, CMAIN_PCB.kicad_sch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]
2026-06-29 fix(cmain): integrate prototype ordering update
    [CAN circuit.kicad_sch, CMAIN_PCB.kicad_pcb, CMAIN_PCB.kicad_sch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]
2026-06-29 fix(cmain): mark GH connector pins passive
    [CMAIN_PCB.kicad_sch]
2026-06-30 fix(cbc): integrate ordered PCB update
    [B08B-JWPF-SK-R.step, C0805_L2.0-W1.3-H1.3.step, C1210_L3.2-W2.5-H2.5.step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]
2026-07-16 feat(cbc): initial ESP32-S3 firmware v0.1.0
    PlatformIO project for the CBC ESP32-S3-WROOM-1-N16R8: precharge +
    latch arm sequence, kill-trigger monitoring, dual MCP2515 (16 MHz)
    CAN init, DroneCAN RX decode (NodeStatus/BatteryInfo) with raw frame
    logging for Tattu protocol identification, NodeStatus broadcast on
    the isolated drone bus (bridge stubbed), 2x DS18B20, serial console.
    Pin map extracted from the ordered-board netlist (PR #51). Compiles
    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
2026-07-16 feat(cbc): decode Tattu vendor CAN broadcast (0x1092)
    Port the battery protocol knowledge from the Quiver RPi tattu bridge
    (tattu_bridge.py): Tattu packs broadcast a DroneCAN v0 multi-frame
    vendor transfer on ext ID 0x01109216 (dtid 0x1092, node 22, 1 Mbps)
    with u16 vendor/model, voltage in mV, current in 10mA, temp in degC,
    SoC in %. The generic reassembler already handled the framing; add
    the payload decoder alongside standard BatteryInfo.
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2026-07-16 firmware: switch to pioarduino platform (Arduino core 3.x) for S3 N16R8 boot fix
2026-07-16 firmware: fix setup hang - construct MCP2515s after SPI.begin (ctor was calling SPI.begin at static-init, breaks on core 3.x)
2026-07-20 params: Caribou standard parameter file forked from Quiver (hexa, PWM ESCs, 18S, no OA, RID enabled)
    [standard-params.param]
2026-07-20 params: disable Remote ID (Julius clarification)
    [standard-params.param]
2026-07-20 params: DroneCAN ESCs primary (PWM backup only), motor mapping confirmed from CMAIN silkscreen, 18S/30Ah confirmed
    [standard-params.param]
2026-07-20 schematic: fix CMAIN text annotation typo IO_CH5 (PWM6) -> IO_CH6 (PWM6)
    [CMAIN_PCB.kicad_sch]
2026-07-21 CBC firmware v0.2.0: Tattu 18S decode + BatteryInfo bridge
    Battery protocol confirmed on hardware (Julius's frame dump, 2026-07-21):
    Tattu "E-UAVCAN" broadcast, ext ID 0x01109216, 1 Mbps, 4 Hz.
    - Fix reassembler for the Tattu quirk: transfer ID increments on every
    frame (strict v0 logic rejected all transfers — the reason v0.1.0
    showed "no telemetry decoded").
    - Full 18S payload parse: voltage (10 mV units — was wrongly mV), current,
    temp, SOC, SOH, cycles, 18 cell voltages, design/remaining mAh, error
    bitfield, serial (76-byte variant).
    - Battery->drone bridge: republish as standard
    uavcan.equipment.power.BatteryInfo @2Hz once allocated (stops when
    telemetry stale >5 s). Cu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
2026-07-21 CBC firmware v0.3.0: NODE_ID/BATT_ID configurable over CAN (DroneCAN GUI tool)
    Julius asked to set the node ID from the DroneCAN GUI tool instead of
    plugging into each ESP32's USB port. This adds the standard DroneCAN
    configuration services so all per-board setup happens over the drone bus:
    - uavcan.protocol.param.GetSet: NODE_ID (0 = dynamic allocation, 1-125 =
    static) and BATT_ID (battery_id tag in the bridged BatteryInfo so the FC
    can tell the 6 packs apart). Read by index or name, integer writes with
    min/max clamping, all-empty response terminates GUI enumeration.
    - uavcan.protocol.param.ExecuteOpcode: SAVE persists both params to ESP32
    NVS flash; ERASE resets to defaults and pe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
2026-07-21 CBC firmware v0.3.1: bridge max temperature of pack + both board sensors
    Julius's request: the FC should see the hottest of the three temperatures
    we know — the Tattu pack's internal sensor and the two DS18B20s on the CBC
    board itself. Previously only the pack temp was bridged; the board sensors
    were console-only. NaN/failed sensors are skipped, so with no DS18B20s
    fitted the behavior is unchanged.
2026-07-22 CBC firmware v0.3.2: drone bus default 500 kbps (battery stays 1 Mbps)
    Julius's call: Caribou's drone bus has long stubs, and 500 kbps gives more
    signal margin on a large airframe than the 1 Mbps DroneCAN convention. The
    battery bus stays at 1 Mbps (fixed Tattu rate). FC side must match with
    CAN_P1_BITRATE=500000. Runtime override still available via the serial
    `bitrate drone` command.
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2026-07-22 docs: update CBC README to match the ordered board revision
    - MCU: ESP32-C3-MINI-1 -> ESP32-S3-WROOM-1 (U301)
    - CAN transceivers: SN65HVD230 -> TJA1049T/3J (drone) + ADM3053BRWZ isolated (battery)
    - MCP2515 crystals: 8 MHz -> 16 MHz (X401/X402)
    - Battery interface: Prolanv EN60A section -> C90D adapter + HC201/HC202 pads + CN201 battery CAN
    - Signal connector: Amphenol AT13 -> JST B08B-JWPF-SK-R (J501) with verified 8-pin pinout
    - Continuous current: 100A -> 150A (in line with C90D)
    - GPIO allocation: replaced estimate with as-routed pin map from production netlist
    - Fixed stale refs (R16 -> U201 latch/R207, J4/J5 -> J201-J204, AT13 harness -> J501)
2026-07-22 chore: fix CI — dead link in c90d.md and new dictionary words
    - ./cbc -> ./cbc.md (markdown link checker)
    - add BRWZ, GNSS, JWPF, PSRAM, WROOM, Xtensa, multirotor, pinouts to cspell project words
2026-07-22 CBC firmware v0.3.3: fix out-of-order TX frames breaking the GUI tool
    The DroneCAN GUI tool rejected our multi-frame transfers with
    "TransferError: Toggle bit value 0 incorrect on frame 1". Root cause: the
    MCP2515 arbitrates its three TX buffers by buffer number when TXP
    priorities are equal, so when more than one frame of a transfer was queued
    the later buffer could transmit first, reordering frames on the wire. More
    frequent at 500 kbps (frame time doubled, buffers overlap more often).
    Fix: droneSend() now waits for all three TXnREQ bits to clear (READ STATUS
    mask 0x54) before loading the next frame, so multi-frame transfers are
    strictly serialized in wire order. Worst case adds ~2.4 ms t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
2026-10-21 feat(cbc): integrate PT1.5 CBC PCB update for the US build
    Julius's CPC_PCB_21_10_26_5 package (issue #58): precharge ground fix with the new H_PWR-OUT- net and NT201, precharge and HV bus sensing, BZ501 buzzer, aux input inrush limiting (RT601, R628/R629, F604), BOM-review part swaps, and JLC production outputs. The board STEP is zipped because the raw export is 127 MB, which is over GitHub's 100 MB file limit.
